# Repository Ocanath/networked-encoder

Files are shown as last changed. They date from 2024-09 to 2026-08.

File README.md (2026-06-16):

# Networked Encoder

A compact RS-485 magnetic encoder system powered by [DARTT](https://github.com/ocanath/dartt-protocol), designed for daisy-chaining multiple encoder nodes on a shared bus. The system consists of STM32-based firmware, a host-side C++ API, and a CLI tool for calibration, address assignment, and firmware flashing.

## What it does

Each encoder node sits on an RS-485 bus and responds to two address classes:

- **Motor address** — a minimal framing mode optimized for high-rate angle polling, intended for real-time motion control.
- **Misc address** — full DARTT register access for calibration (sin/cos bounds, angular offset, orthogonality error), device control (save to flash, restart, enter bootloader), and diagnostics.

Addresses are assigned per-device and persisted to flash. The bootloader (also DARTT-based) supports firmware updates over the same RS-485 bus with no additional hardware interface.

## Repository Structure

| Path | Contents |
|---|---|
| `embedded/encoder-rs485` | STM32G031 encoder application firmware |
| `embedded/encoder-bootloader` | DARTT-based RS-485 bootloader |
| `api/` | Host-side C++ encoder controller library |
| `cli/` | Command-line tool for calibration, addressing, and flashing |
| `scripts/` | Helper scripts for first-time device setup and firmware updates |

## Dependencies

The API and CLI pull in three submodules under `api/external/`:

| Submodule | Purpose |
|---|---|
| [`dartt-protocol`](https://github.com/ocanath/dartt-protocol) | DARTT framing, parsing, read/write helpers |
| [`byte-stuffing`](https://github.com/ocanath/byte-stuffing) | COBS encode/decode |
| [`serial-cross-platform`](https://github.com/ocanath/serial-cross-platform) | Cross-platform serial port |

Initialize all submodules after cloning with `git submodule update --init --recursive`.

## Building

Requires CMake 3.22+ and a C++20-capable compiler. The primary build target is `encoder-cli`. VSCode launch and build tasks are provided in `.vscode/`.

## CLI

The CLI (`encoder-cli`) takes a DARTT device address as its first argument followed by a port and baud rate. It supports streaming angle data, reading raw ADC values, running an interactive calibration session, reassigning device addresses, and flashing firmware over RS-485 via the bootloader. Run `encoder-cli --help` for the full command reference.

## First-time Device Setup

Use `scripts/init_flash.sh` to set up a brand-new device. The bootloader ships at address 255 and the encoder application defaults to address 0. The script flashes firmware, starts the application, then assigns a permanent address. For subsequent updates on an already-configured device, use `scripts/update_firmware.sh`.

## Using the API

`api/` is designed to be consumed as a CMake `add_subdirectory` dependency. Link against `encoder_controller` and construct an `Encoder` object with the device address and a pointer to an already-connected `Serial` object. The caller owns the `Serial` lifetime.

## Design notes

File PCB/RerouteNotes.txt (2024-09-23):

1. Break pads out to the encoder case for programming
2. instead of terminating fsr wires at current location, split another branch out at 90 degrees and wrap it to the top of the encoder case so the existing 
	wire guides/channel can be used; it just terminates the wires at a different location
3. add a branch somewhere for the temperature sensor

4. Do board to board connector for the aenc to the new 12mm motor encoder, like how in phones are done like yeah good
5. 7pin df52 exits 12mm motor encoder, and does df52 to pico-blade to hand. 7pin has 3.3, gnd, UART, cos, sin, SDA, SCL. SDA and SCL are normally unpopulated
6. for the fsr foldover, do a picolock that sits on the top of the drive train case as well as a solder version

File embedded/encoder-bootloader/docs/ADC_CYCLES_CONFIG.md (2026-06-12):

# ADC Sample Time Configuration

## This section was written by a human

WARNING: This document was fully generated by claude. Review the contents before acting on them.

I haven't been thinking about the cycle time for SAR adc's right. It's about impedance matching/settling time... claude caught this in a review and it's something to think about.

## Background

The STM32G031 ADC requires a minimum sampling time for the internal sampling
capacitor to charge to within 0.5 LSB of the input voltage. The required time
depends on source impedance:

```
t_SAMPLE ≥ (R_ADC + R_SOURCE) × C_ADC × ln(2^(N+2))
```

**G031 constants** (from RM0444 / DS12994):
- `R_ADC` ≈ 6 kΩ (internal switch resistance)
- `C_ADC` ≈ 7 pF (sampling capacitor)
- `N` = 12 (ADC resolution in bits)
- `ln(2^14)` ≈ 9.70

**ADC clock**: PCLK/2 = 64 MHz/2 = **32 MHz** → 1 cycle = 31.25 ns

## Source Impedance vs. Minimum Sample Time

| Sample time | Duration @ 32 MHz | Max R_SOURCE |
|---|---|---|
| 1.5 cycles | 47 ns | insufficient for any source |
| 7.5 cycles | 234 ns | insufficient |
| 12.5 cycles | 391 ns | ~0 Ω |
| 19.5 cycles | 609 ns | ~3 kΩ |
| **39.5 cycles** | **1234 ns** | **~12 kΩ** |
| 79.5 cycles | 2484 ns | ~31 kΩ |

## Current Setting

`ADC_SAMPLETIME_39CYCLES_5` — chosen to cover direct encoder outputs and
typical RC anti-alias filter resistors (e.g. 4.7 kΩ series + shunt cap).

With 4× oversampling this yields a total conversion time of:

```
4 × (39.5 + 12.5) = 208 ADC cycles ≈ 6.5 µs per channel
2 channels × 6.5 µs ≈ 13 µs per DMA batch
```

## Recalculating for a Different Source Impedance

Solve for the minimum number of ADC cycles:

```
t_SAMPLE = (R_ADC + R_SOURCE) × C_ADC × ln(2^14)
         = (6000 + R_SOURCE) × 7e-12 × 9.70

cycles = ceil(t_SAMPLE × f_ADC) + 0.5   (round up to next available setting)
```

Then pick the next available `ADC_SAMPLETIME_*` value above that cycle count.
If source impedance is unknown, measure or bound it from the schematic
(series resistors, output driver spec of the encoder IC).

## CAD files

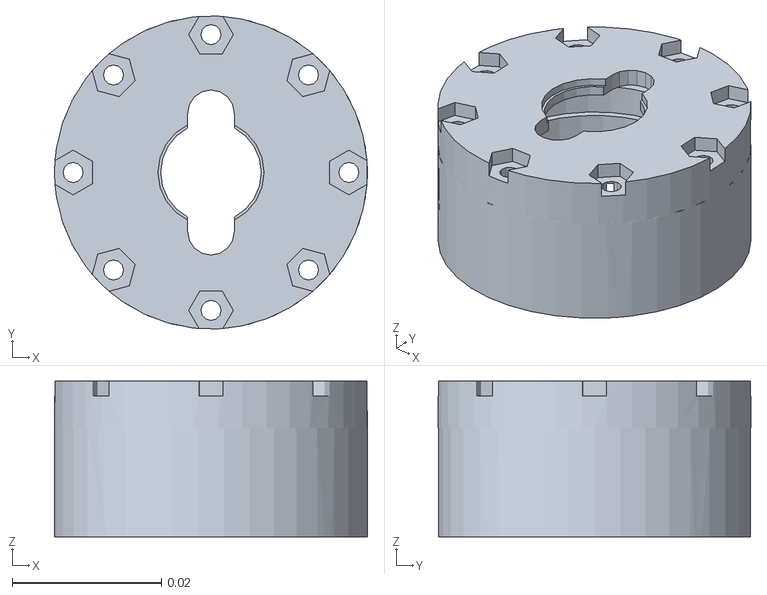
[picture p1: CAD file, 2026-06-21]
CAD/stl/stator-coarse.STL
0.042 x 0.042 x 0.0209

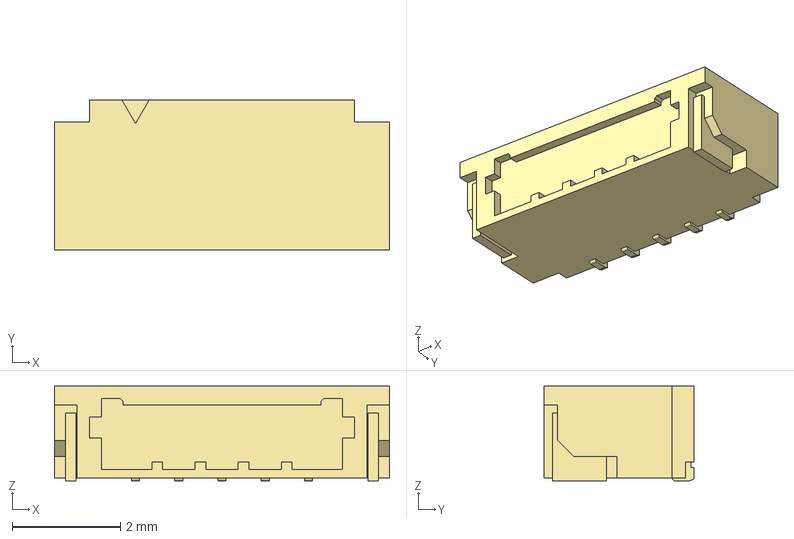
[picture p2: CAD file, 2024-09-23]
PCB/3dModels/DF52 CAD Download/DF52-5S-0.8H.stp
6.20 x 2.77 x 1.75 mm

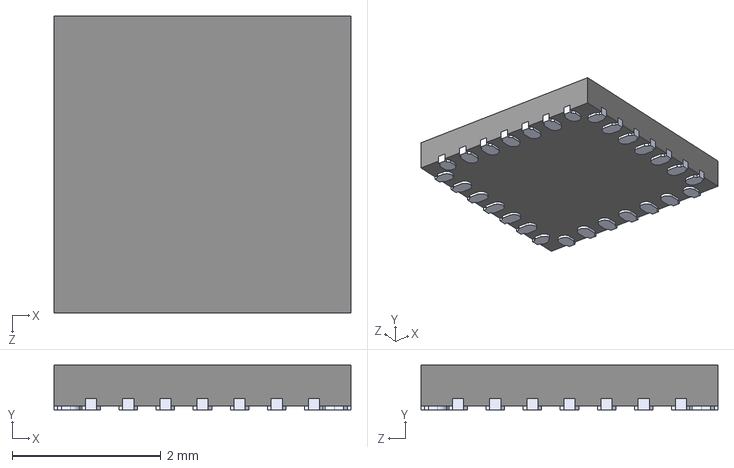
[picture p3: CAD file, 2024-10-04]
PCB/3dModels/STM32G031G6U6.step
4.00 x 0.6 x 4.00 mm

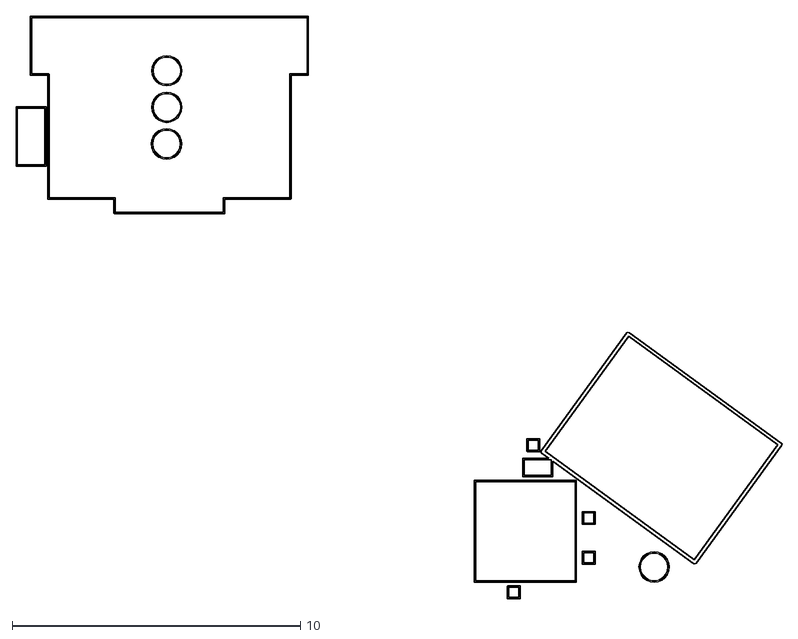
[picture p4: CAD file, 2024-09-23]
PCB/stiffener/adapter-encoder-pcb-F_Courtyard.dxf
26.6 x 20.2

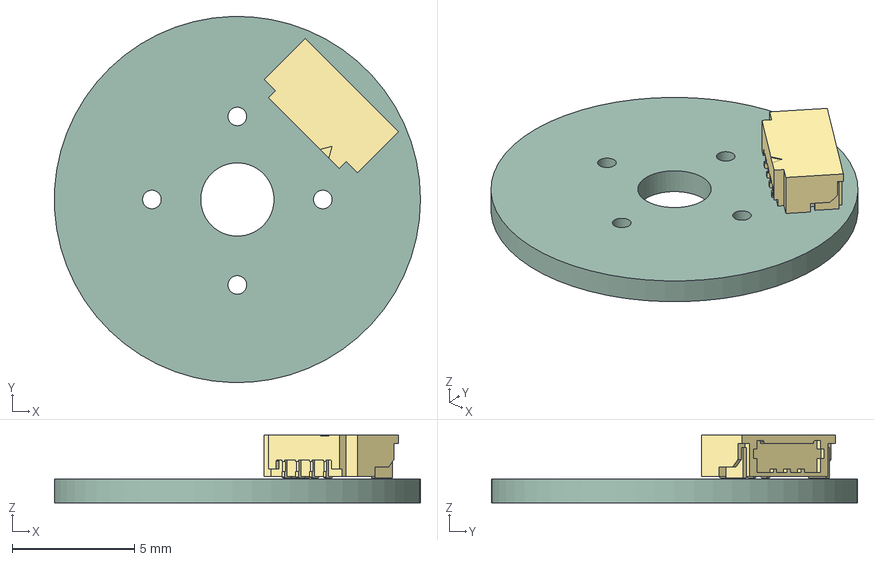
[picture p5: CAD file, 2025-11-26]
PCB/z1-encoder-passthrough-pcb.step
15.0 x 15.0 x 2.78 mm
z1-encoder-passthrough-pcb PCB

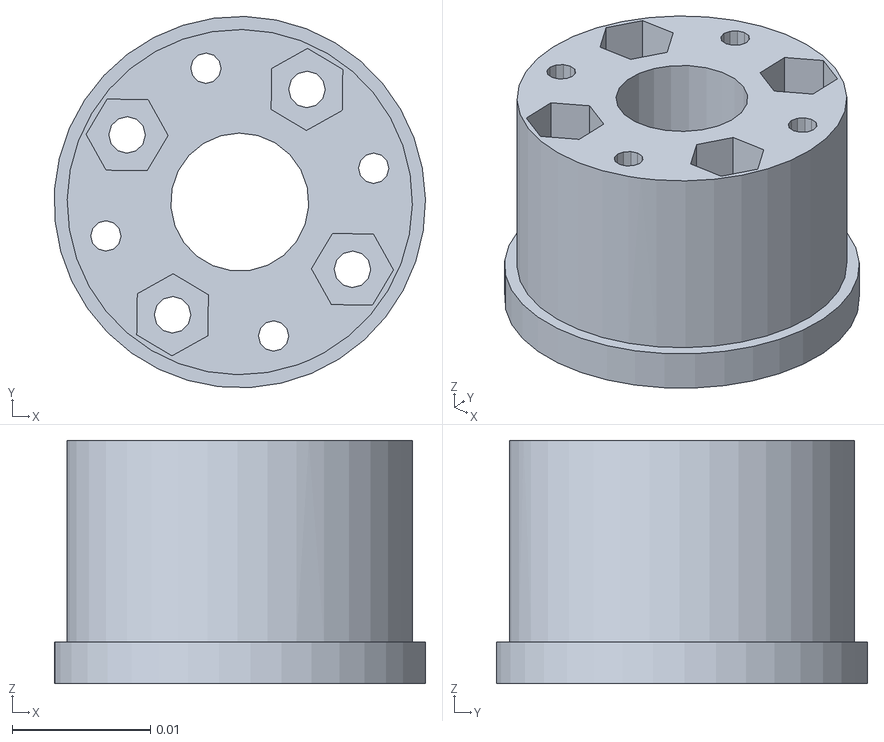
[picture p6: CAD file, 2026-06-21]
CAD/stl/rotor-coarse.STL
0.0269 x 0.0269 x 0.0176

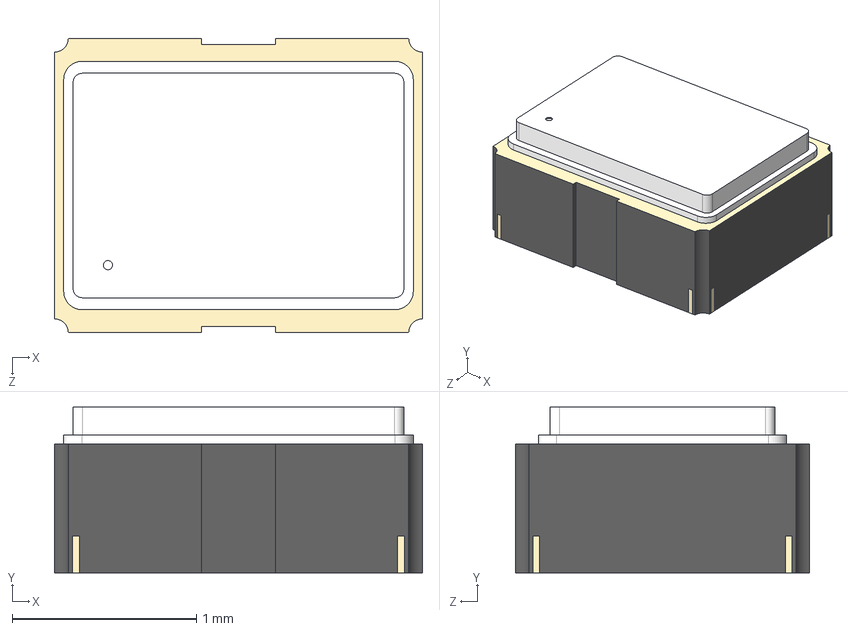
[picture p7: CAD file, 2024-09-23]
PCB/3dModels/ECS-1633-480-BN-TR.STEP
2.00 x 0.9 x 1.60 mm

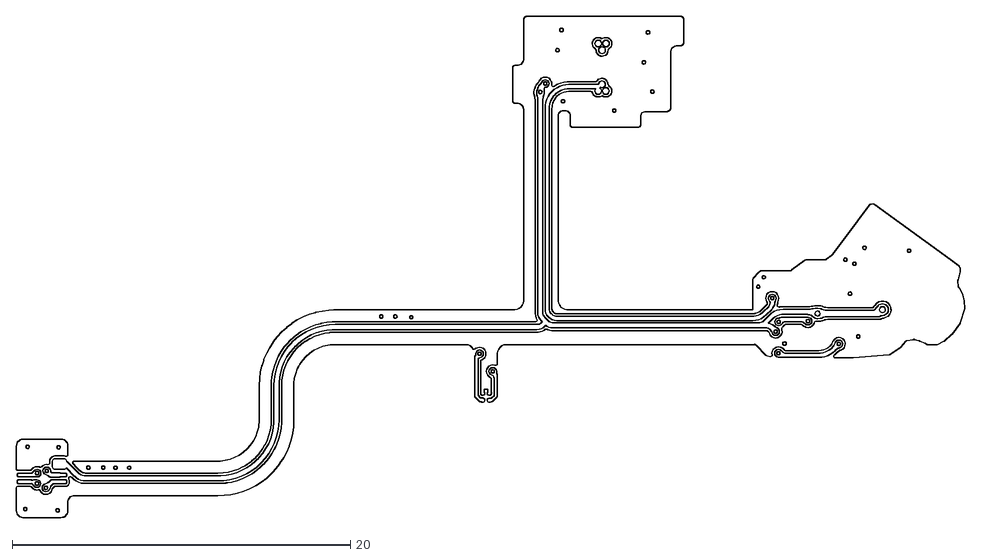
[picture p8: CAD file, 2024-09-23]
PCB/stiffener/adapter-encoder-pcb-B_Cu.dxf
56.0 x 29.6

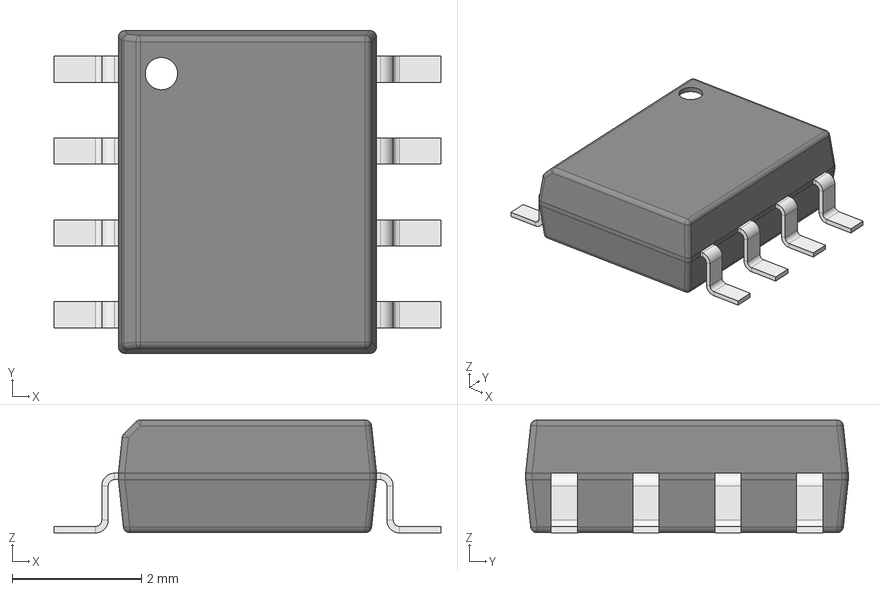
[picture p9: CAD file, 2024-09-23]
PCB/3dModels/SOIC127P600X175-8L.step
6.00 x 5.00 x 1.75 mm
Leader x 8

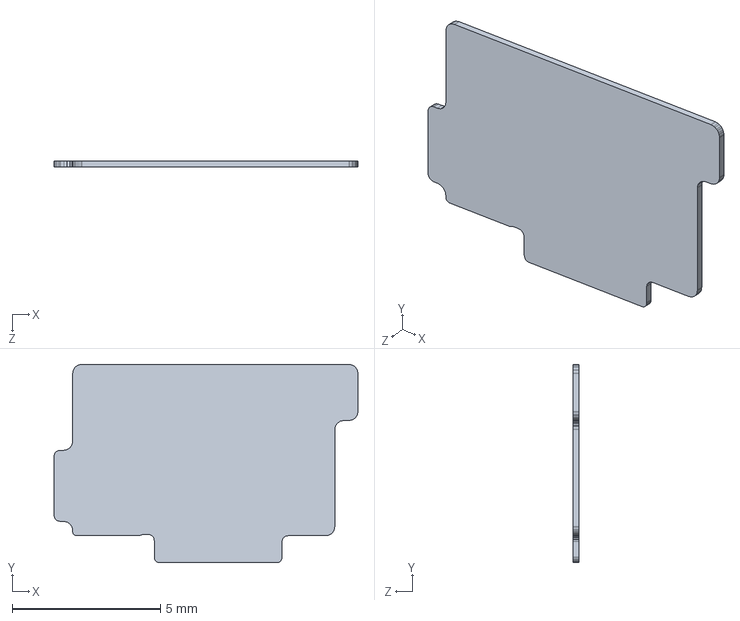
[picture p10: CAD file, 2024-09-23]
PCB/stiffener/Stiffener-4.SLDPRT
10.3 x 6.69 x 0.2 mm

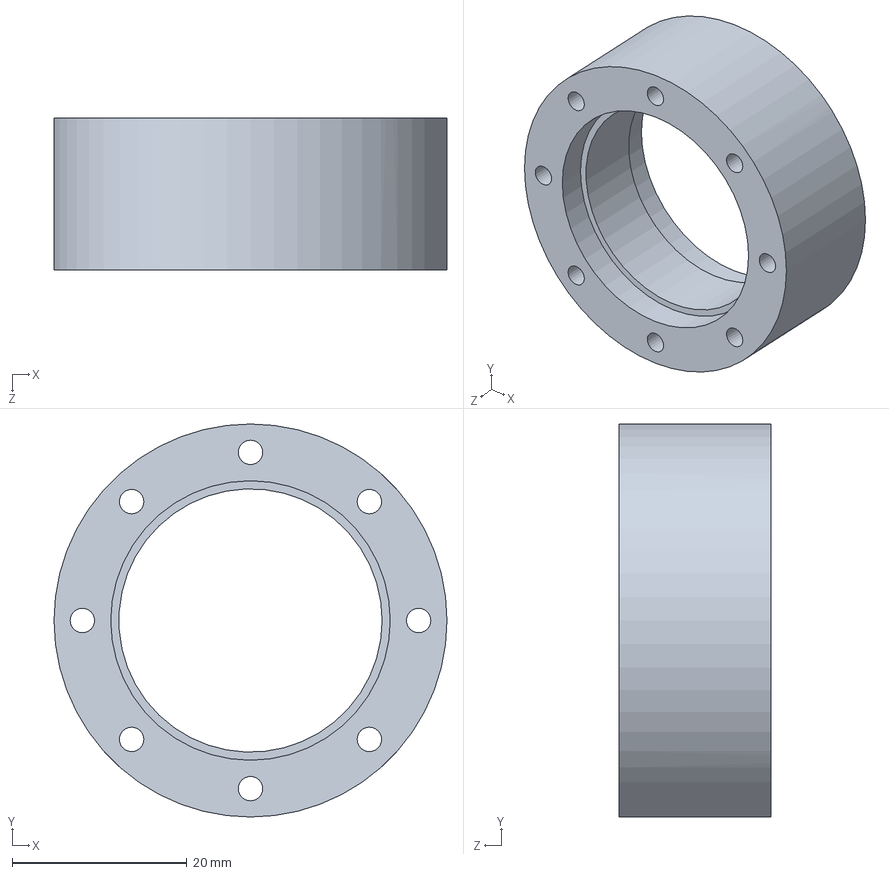
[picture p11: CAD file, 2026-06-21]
CAD/BEARING-SEATS.SLDPRT
45.0 x 45.0 x 17.4 mm

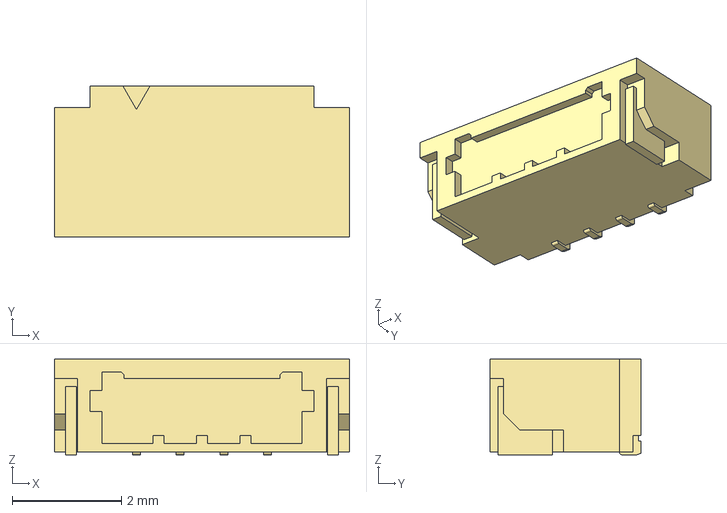
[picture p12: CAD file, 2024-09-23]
PCB/3dModels/DF52-4S-0.8H.stp
5.40 x 2.77 x 1.75 mm

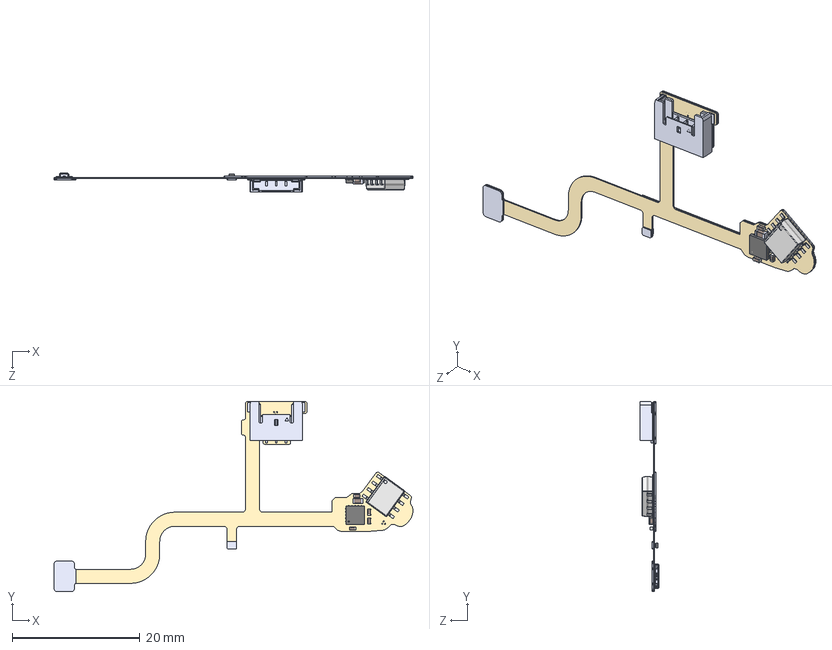
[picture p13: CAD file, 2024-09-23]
PCB/stiffener/adapter-encoder-pcb-outline.STEP
56.2 x 29.8 x 2.91 mm
SOLID^C_0402_1005Metric_adapter-encoder-pcb-outline(2)_adapter-encoder-pcb-outline x 4
SOLID-0^C_0603_1608Metric_adapter-encoder-pcb-outline(2)_adapter-encoder-pcb-outline
SOLID-1^ST_UFQFPN-20_3x3mm_P0.5mm_adapter-encoder-pcb-outline(2)_adapter-encoder-pcb-outline
COMPOUND^SOIC127P600X175-8L_adapter-encoder-pcb-outline(2)_adapter-encoder-pcb-outline
COMPOUND-2^5040500391_adapter-encoder-pcb-outline(2)_adapter-encoder-pcb-outline
SOLID-3^WLP-4_0.83x0.83mm_P0.4mm_adapter-encoder-pcb-outline(2)_adapter-encoder-pcb-outline
SOLID-4^c-2386587-1-1-3d_adapter-encoder-pcb-outline(2)_adapter-encoder-pcb-outline
_autosave-adapter-encoder-pcb PCB^adapter-encoder-pcb-outline(2)_adapter-encoder-pcb-outline
Stiffener-1
Stiffener-2
Stiffener-3
Stiffener-4

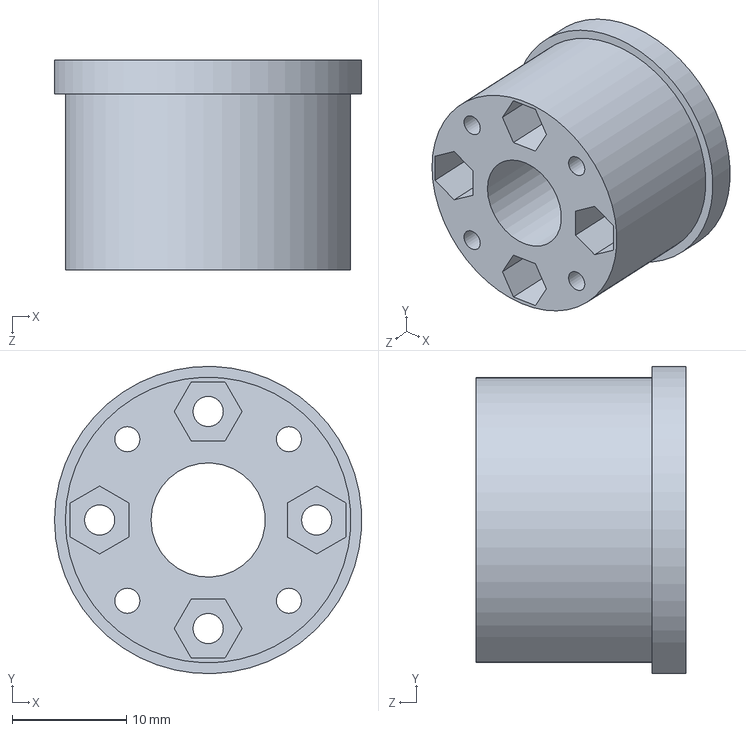
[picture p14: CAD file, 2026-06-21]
CAD/SHAFT.SLDPRT
26.9 x 26.9 x 18.4 mm

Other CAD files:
CAD/encoder.SLDASM
CAD/z1-encoder-passthrough-pcb.step.SLDPRT
PCB/3dModels/c-2386586-1-1-3d.stp
PCB/stiffener/adapter-encoder-pcb-User_4.dxf
CAD/6656K108_Ultra-Thin Ball Bearing.SLDPRT
CAD/90591A265_Zinc-Plated Steel Hex Nut.SLDPRT
CAD/90591A270_Zinc-Plated Steel Hex Nut.SLDPRT
CAD/91290A108_Alloy Steel Socket Head Screw.SLDPRT
CAD/91292A031_18-8 Stainless Steel Socket Head Screw.SLDPRT
CAD/PCBHOLDER.SLDPRT
CAD/adapter-encoder-pcb-outline.step.SLDPRT
CAD/fenc-ring-magnet.SLDPRT
PCB/3dModels/5040500391.step
PCB/3dModels/532610471.stp
PCB/3dModels/ASV.step
PCB/3dModels/CAP_8SIZECODEF.stp
PCB/3dModels/C_0402_1005Metric.step
PCB/3dModels/C_0603_1608Metric.step
PCB/3dModels/DF52-8S-0.8H_21_.step
PCB/3dModels/DFN-10-1EP_3x3mm_P0.5mm_EP1.65x2.38mm.step
PCB/3dModels/DI100N10PQ.STEP
PCB/3dModels/LED_0603_1608Metric.step
PCB/3dModels/PCC-M0530M-LP.STEP
PCB/3dModels/RNM0015A.stp
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

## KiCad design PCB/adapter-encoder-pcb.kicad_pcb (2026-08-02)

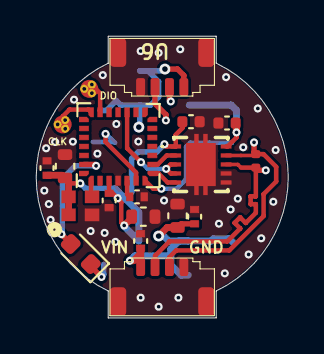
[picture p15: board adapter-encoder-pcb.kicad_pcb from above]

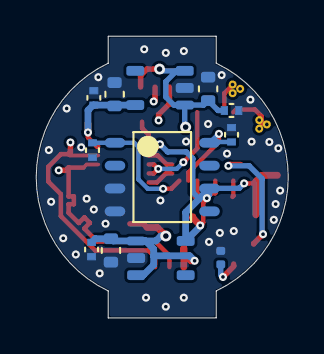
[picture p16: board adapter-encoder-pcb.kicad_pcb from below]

Board: 4 copper layers, 14.0 x 15.6 mm, 31 parts (12 on the bottom side), 17 nets.

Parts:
C1, C8, C10, C12, C15, C17: 4.7uF; C_0603_1608Metric
C2, C3, C4, C5, C6, C7, C9, C11, C13, C14, C16, C18: 100nF; C_0402_1005Metric
D1: LED; LED_0603_1608Metric
IC1: THVD2410VDRCR
M1, M2: THRU_HOLE_PAD; PAD-SMT-SMALL
R1: Resistor; R_0402_1005Metric
R3: 120; R_0402_1005Metric
U1: TLE5009E1000FUMA1; SOIC8-TLE5009
U2: STM32G031G6U6; UFQFPN28
U3, U6: DF52-4S-0.8H(21)
U4, U7: SPX3819M5-L-3-3; SOT-23-5
U5: C2901617; ECS-1633-480-BN-TR

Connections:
+3V3: C1.1, C3.1, C6.2, C12.1, C13.1, IC1.1 (VIO), U1.6 (Vdd), U2.3 (VDD), U4.5 (VOUT), U5.1 (Enable/Disable), U5.4 (VDD)
/+5V0: C7.2, C16.1, C17.1, IC1.10 (VCC), U7.5 (VOUT)
/COS: C2.1, U1.1 (COS_P), U2.7 (PA1)
/LED_GPIO: D1.2 (A), U2.27 (PB7)
/RS485+: IC1.8 (A), R3.1, U3.2, U6.2
/RS485-: IC1.9 (B), R3.2, U3.3, U6.3
/RX: IC1.2 (R), U2.9 (PA3)
/SIN: C4.1, U1.8 (SIN_P), U2.6 (PA0)
/SWCLK: M2.1, U2.20 (PA13)
/SWDIO: M1.1, U2.21 (PA14-BOOT0)
/TX: IC1.5 (D), U2.8 (PA2)
/UART1_DE: IC1.3 (DE), IC1.4 (~RE), U2.17 (PC6)
/Vin: C8.1, C9.1, C10.1, C11.1, C14.1, C15.1, C18.1, U3.1, U4.1 (VIN), U4.3 (EN), U6.1, U7.1 (VIN), U7.3 (EN)
GND: C1.2, C2.2, C3.2, C4.2, C5.2, C6.1, C7.1, C8.2, C9.2, C10.2, C11.2, C12.2, C13.2, C14.2, C15.2, C16.2, C17.2, C18.2, IC1.6 (GND), IC1.7 (SLR), IC1.11 (EP_1), IC1.12 (EP_2), IC1.13 (EP_3), IC1.14 (EP_4), IC1.15 (EP_5), R1.2, U1.3 (GND2), U1.4 (GND1), U2.4 (VSS), U3.4, U3.5 (MNT), U3.6 (MNT), U4.2 (GND), U5.2 (GND/Case), U6.4, U6.5 (MNT), U6.6 (MNT), U7.2 (GND)
unnamed: D1.1 (K), R1.1
unnamed: U2.1 (PC14-OSC32_IN), U5.3 (OUTPUT)
unnamed: C5.1, U2.5 (PF2-NRST)

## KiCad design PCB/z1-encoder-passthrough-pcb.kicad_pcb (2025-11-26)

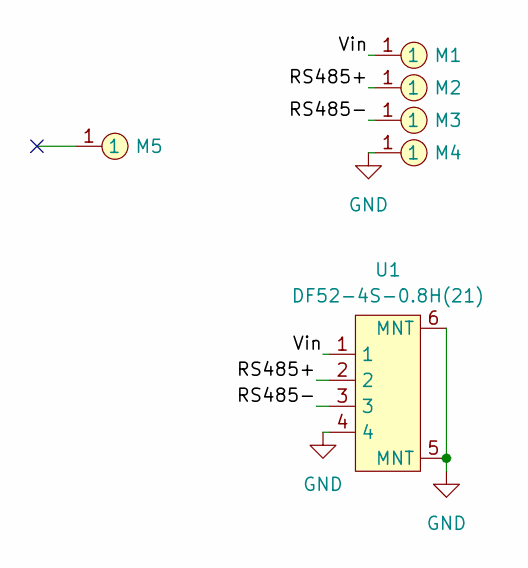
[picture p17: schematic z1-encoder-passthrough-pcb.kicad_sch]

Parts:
M1, M2, M3, M4: THRU_HOLE_PAD; THRU_HOLE
M5: THRU_HOLE_PAD; MECH_THRU_HOLE
U1: DF52-4S-0.8H(21)

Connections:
/RS485+: M2.1, U1.2
/RS485-: M3.1, U1.3
/Vin: M1.1, U1.1
GND: M4.1, U1.4, U1.5 (MNT), U1.6 (MNT)

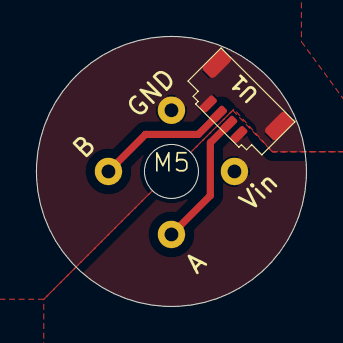
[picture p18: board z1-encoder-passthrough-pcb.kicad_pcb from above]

Board: 2 copper layers, 15.0 x 15.0 mm, 6 parts (0 on the bottom side), 4 nets.

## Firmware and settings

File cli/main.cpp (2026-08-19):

#include <iostream>
#include <string>
#include <signal.h>
#include "args.h"

static volatile sig_atomic_t g_stop = 0;
static void on_sigint(int) { g_stop = 1; }
#include "encoder.h"
#include "dartt_map.h"
#include "dartt_flasher.h"
#include "serial.h"

int main(int argc, char ** argv)
{
    cli_args_t a;
    parse_args(argc, argv, a);

    Serial ser;
    if (a.port) ser.connect(a.port, a.baud);
    else        ser.autoconnect(a.baud);

    Encoder enc(a.addr, &ser);

    if (a.read_angle)
    {
        while(1)
        {
            // int rc = enc.read_angle_misc();
			int rc = enc.read_angle();
            if(rc == 0)
            {
                printf("theta= %f\n", enc.theta);
            }
            else
            {
                printf("Error reading from encoder %d\n", rc);
            }
        }
    }
    if (a.read_angle_misc)
    {
        while(1)
        {
            int rc = enc.read_angle_misc();
            if(rc == 0)
            {
                printf("theta= %f\n", enc.theta);
            }
            else
            {
                printf("Error reading from encoder %d\n", rc);
            }
        }
    }
    if (a.read_adc)
    {
        while(1)
		{
			int rc = enc.read_adc_raw();
			if(rc == 0)
			{
				printf("[%d %d]\n", enc.dp_periph.dma_adc_raw[0], enc.dp_periph.dma_adc_raw[1]);
			}
			else
			{
				printf("Error reading %d\n", rc);
			}
		}
    }
    if (a.read_fds)
    {
        printf("Placeholder: TODO read out fds\n");
    }
    if (a.set_zero)
    {
        printf("Zero out encoder\n");
		float avg = 0;
		int nsamples = 0;
		int rc = 0;
		for(int ang_sample = 0; ang_sample < 1000; ang_sample++)
		{
			rc = enc.read_angle_misc();
			if(rc == 0)
			{
				avg += enc.dp_periph.angle;
				nsamples++;
			}
		}
		avg = avg / (float)nsamples;
		printf("avg = %f\n", avg);

		dartt_mem_t offset_slice ={.buf = (unsigned char *)&enc.dp_ctl.fds.offset,
			.size = sizeof(enc.dp_ctl.fds.offset)
		};
		rc = dartt_read_multi(&offset_slice, &enc.ds);
		if(rc != 0) 
		{
			printf("issue reading offset, abort\n");
			return -1;
		}
		printf("offset is equal to %d\n",enc.dp_periph.fds.offset);
		float offset = (float)enc.dp_periph.fds.offset;
		float raw = avg + offset;
		enc.dp_ctl.fds.offset = (int32_t)raw;

		rc = dartt_write_multi(&offset_slice, &enc.ds);
		printf("Wrote %d as offset\n", enc.dp_ctl.fds.offset);
		rc = enc.write_action_flag(FS_SAVE);
		if(rc != 0) {printf("FS_SAVE failed: %d\n", rc);}
		else{printf("Updated filesystem successfully\n");}


    }
    if (a.calibrate)
    {
		signal(SIGINT, on_sigint);
		int32_t sinmin = 1<<14;
		int32_t sinmax = 0;
		int32_t cosmin = 1 << 14;
		int32_t cosmax = 0;
		while(!g_stop)
		{
			int rc = enc.read_adc_raw();
			if(rc != 0)
			{
				printf("Error reading %d\n", rc);
			}
			int32_t c = enc.dp_periph.dma_adc_raw[0];
			int32_t s = enc.dp_periph.dma_adc_raw[1];
			if(c < cosmin)
			{
				cosmin = c;
			}
			if(c > cosmax)
			{
				cosmax = c;
			}
			if(s < sinmin)
			{
				sinmin = s;
			}
			if(s > sinmax)
			{
				sinmax = s;
			}
			printf("min = [%d, %d], max = [%d, %d]\n", cosmin, sinmin, cosmax, sinmax);
		}
		printf("\nFinal: cos=[%d, %d] sin=[%d, %d]\n", cosmin, cosmax, sinmin, sinmax);
		enc.dp_ctl.fds.cos_min = cosmin;
		enc.dp_ctl.fds.cos_max = cosmax;
		enc.dp_ctl.fds.sin_min = sinmin;
		enc.dp_ctl.fds.sin_max = sinmax;
		dartt_mem_t sincos_minmax = {
			.buf = (unsigned char *)(&enc.dp_ctl.fds.sin_min),
			.size = 4*sizeof(uint32_t)
		};
		int rc = dartt_write_multi(&sincos_minmax, &enc.ds);
		// int rc = enc.write_fds();
		if(rc != 0) printf("write_fds failed: %d\n", rc);
		rc = enc.write_action_flag(FS_SAVE);
		if(rc != 0) printf("FS_SAVE failed: %d\n", rc);
    }
    if (a.restart)
    {
		int	rc = enc.write_action_flag(RESTART);
		if(rc != 0) printf("RESTART failed: %d\n", rc);

    }
    if (a.bootload)
    {
		int	rc = enc.write_action_flag(BOOTLOAD);
		if(rc != 0) printf("BOOTLOAD failed: %d\n", rc);
    }
    if (a.set_address)
    {
        printf("Placeholder: set address to %d\n", a.new_address);

		enc.dp_ctl.fds.address = a.new_address;
		dartt_mem_t addr = {
			.buf = (unsigned char *)(&enc.dp_ctl.fds.address),
			.size = sizeof(enc.dp_ctl.fds.address)
		};
		int rc = dartt_write_multi(&addr, &enc.ds);
		if(rc != 0 ){printf("address update failed: %d\n", rc);}
		//TODO: add write action to update flash HERE but don't do it yet to avoid brickage
		rc = enc.write_action_flag(FS_SAVE);
		if(rc != 0 ){printf("settings save failed code: %d\n", rc);}

		//set long timeout and read back address to confirm
		enc.ds.timeout_ms = 1000;
		rc = dartt_read_multi(&addr, &enc.ds);
		if(rc != 0){printf("Readback post save failed: %d\n", rc);}
		if(enc.dp_periph.fds.address != a.new_address)
		{
			printf("Failed to write - readback mismatch. desired %d, actual %d\n", a.new_address, enc.dp_periph.fds.address);
		}
		else
		{
			printf("Readback match\n");
		}
		
		rc = enc.write_action_flag(BOOTLOAD);
		if(rc != 0 ){printf("bootload update failed: %d\n", rc);}

		DarttFlasher flasher(a.bootloader_addr, &ser);
		rc = flasher.poll_action_flags(500);
		if(rc < 0)
		{
			printf("Failed to get action flag: %d\n", rc);
			return rc;
		}
		else{printf("bootloader ready, writing address\n");}
		rc = flasher.update_target_address(a.new_address);
		if(rc != 0) {printf("Failed to update bootloader address. Code %d\n", rc);}
		rc = flasher.start_app();
		if(rc != 0) {printf("Failed to start app, code %d\n", rc);}
		printf("Done\n");
    }
    if (a.flash)
    {
        printf("Placeholder: flash %s via bootloader\n", a.filename);
    }
    if (a.bl_version)
    {
        printf("Placeholder: get bootloader version\n");
    }
    if (a.bl_start)
    {
        printf("Placeholder: start application\n");
    }
	if(a.scan)
	{
		for(uint8_t scan_addr = 0; scan_addr < 255; scan_addr++)
		{
			Encoder scan_enc(scan_addr, &ser);
			int s_rc = scan_enc.read_adc_raw();
			if(s_rc == 0)
			{
				printf("Found encoder %d\n", scan_addr);
			}
		}
	}
    return 0;
}

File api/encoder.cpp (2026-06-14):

#include "encoder.h"
#include "uart_config.h"

#define NUM_BYTES_COBS_OVERHEAD	2

Encoder::Encoder(unsigned char addr, Serial * ser)
{
	ds.address = addr;

	ds.ctl_base.buf = (unsigned char *)(&dp_ctl);
	ds.ctl_base.size = sizeof(dartt_map_t);
	ds.periph_base.buf = (unsigned char *)(&dp_periph);
	ds.periph_base.size = sizeof(dartt_map_t);
	for(int i = 0; i < (int)sizeof(dartt_map_t); i++)
	{
		ds.ctl_base.buf[i] = 0;
		ds.periph_base.buf[i] = 0;
	}

	tx_buf_mem = new unsigned char[UART_BUF_SIZE];
	rx_buf_mem = new unsigned char[UART_BUF_SIZE];

	ds.base_offset = 0;
	ds.msg_type = TYPE_SERIAL_MESSAGE;
	ds.tx_buf.buf = tx_buf_mem;
	ds.tx_buf.size = UART_BUF_SIZE - NUM_BYTES_COBS_OVERHEAD;
	ds.tx_buf.len = 0;
	ds.rx_buf.buf = rx_buf_mem;
	ds.rx_buf.size = UART_BUF_SIZE - NUM_BYTES_COBS_OVERHEAD;
	ds.rx_buf.len = 0;
	ds.blocking_tx_callback = &network_encoder::tx_blocking;
	ds.user_context_tx = (void*)(ser);
	ds.blocking_rx_callback = &network_encoder::rx_blocking;
	ds.user_context_rx = (void*)(ser);
	ds.timeout_ms = 10;

	theta = 0.f;

	angle_slice = {
		.buf = (unsigned char *)(&dp_ctl.angle),
		.size = sizeof(dp_ctl.angle),
	};
	adc_slice = {
		.buf = (unsigned char *)(&dp_ctl.dma_adc_raw[0]),
		.size = sizeof(dp_ctl.dma_adc_raw),
	};
	ms_slice = {
		.buf = (unsigned char *)(&dp_ctl.tick),
		.size = sizeof(dp_ctl.tick),
	};
	fds_slice = {
		.buf = (unsigned char *)(&dp_ctl.fds),
		.size = sizeof(dp_ctl.fds),
	};
	offset_slice = {
		.buf = (unsigned char *)(&dp_ctl.fds.offset),
		.size = sizeof(dp_ctl.fds.offset),
	};
	action_slice = {
		.buf = (unsigned char * )(&dp_ctl.action_flag),
		.size = sizeof(dp_ctl.action_flag)
	};
}

Encoder::~Encoder()
{
	delete[] tx_buf_mem;
	delete[] rx_buf_mem;
}

int Encoder::read_angle(void)
{
	Serial * ser = (Serial*)(ds.user_context_tx);
	ds.tx_buf.len = 0;
	ds.tx_buf.buf[ds.tx_buf.len++] = ds.address;
	int rc = append_crc(&ds.tx_buf);
	if(rc != DARTT_PROTOCOL_SUCCESS){return rc;}
	cobs_buf_t cb_tx = {
		.buf = ds.tx_buf.buf,
		.size = ds.tx_buf.size,
		.length = ds.tx_buf.len,
		.encoded_state = COBS_DECODED
	};
	rc = cobs_encode_single_buffer(&cb_tx);
	if(rc != DARTT_PROTOCOL_SUCCESS){return rc;}
	ser->write(cb_tx.buf, cb_tx.length);

	cobs_buf_t cb_enc =
	{
		.buf = ds.rx_buf.buf,
		.size = UART_BUF_SIZE,
		.length = 0
	};

	rc = ser->read_until_delimiter(cb_enc.buf, cb_enc.size, 0, ds.timeout_ms);
	if (rc >= 0)
	{
		cb_enc.length = rc;
	}
	else if (rc == -2)
	{
		return -7;
	}
	else
	{
		return -1;
	}
	cobs_buf_t cb_dec =
	{
		.buf = ds.rx_buf.buf,
		.size = ds.rx_buf.size,
		.length = 0
	};
	rc = cobs_decode_double_buffer(&cb_enc, &cb_dec);
	ds.rx_buf.len = cb_dec.length;
	if(rc != COBS_SUCCESS)
	{
		return rc;
	}
	if(cb_dec.buf[0] != MASTER_MOTOR_ADDRESS)
	{
		printf("addr mismatch\n");
	}
	uint16_t raw = (uint16_t)cb_dec.buf[1] | ((uint16_t)cb_dec.buf[2] << 8);
	theta = ((float)(int16_t)raw) / ((float)(1 << 13));
	return 0;
}

int Encoder::read_angle_misc(void)
{
	int rc = dartt_read_multi(&angle_slice, &ds);
	if(rc != DARTT_PROTOCOL_SUCCESS)
	{
		return rc;
	}
	theta = ((float)dp_periph.angle) / ((float)(1 << 14));
	return rc;
}

int Encoder::write_action_flag(uint32_t action)
{
	dp_ctl.action_flag = action;
	return dartt_write_multi(&action_slice, &ds);
}

int Encoder::read_adc_raw(void)
{
	return dartt_read_multi(&adc_slice, &ds);
}

int Encoder::read_time_data(void)
{
	return dartt_read_multi(&ms_slice, &ds);
}

int Encoder::write_fds(void)
{
	return dartt_write_multi(&fds_slice, &ds);
}

int Encoder::write_offset(void)
{
	return dartt_write_multi(&offset_slice, &ds);
}

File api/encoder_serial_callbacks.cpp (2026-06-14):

#include "encoder_serial_callbacks.h"
#include "serial.h"
#include <cstdio>
#include "uart_config.h"

namespace network_encoder {

int tx_blocking(unsigned char addr, dartt_buffer_t * b, void * user_context, uint32_t timeout)
{
	if(user_context == NULL)
	{
		return -2;
	}
	Serial * pser = (Serial*)(user_context);
	if(pser->connected() == false)
	{
		return -2;
	}
	cobs_buf_t cb = {
		.buf = b->buf,
		.size = UART_BUF_SIZE,
		.length = b->len,
		.encoded_state = COBS_DECODED
	};
	int rc = cobs_encode_single_buffer(&cb);
	if (rc != 0)
	{
		return rc;
	}

	rc = pser->write(cb.buf, (int)cb.length);
	if(rc == (int)cb.length)
	{
		return DARTT_PROTOCOL_SUCCESS;
	}
	else
	{
		return -1;
	}
}

int rx_blocking(dartt_buffer_t * buf, void * user_context, uint32_t timeout)
{
	if(user_context == NULL)
	{
		return -2;
	}
	Serial * pser = (Serial*)(user_context);
	if(pser->connected() == false)
	{
		return -2;
	}

	cobs_buf_t cb_enc =
	{
		.buf = buf->buf,
		.size = UART_BUF_SIZE,
		.length = 0
	};

	int rc;
	rc = pser->read_until_delimiter(cb_enc.buf, cb_enc.size, 0, timeout);

	if (rc >= 0)
	{
		cb_enc.length = rc;
	}
	else if (rc == -2)
	{
		return -7;
	}
	else
	{
		return -1;
	}

	cobs_buf_t cb_dec =
	{
		.buf = buf->buf,
		.size = buf->size,
		.length = 0
	};
	rc = cobs_decode_double_buffer(&cb_enc, &cb_dec);
	buf->len = cb_dec.length;

	if (rc != COBS_SUCCESS)
	{
		return rc;
	}
	else
	{
		return DARTT_PROTOCOL_SUCCESS;
	}
}

} // namespace network_encoder

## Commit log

2024-09-23 init commit
    [101-003 M3 T-ULPS.SLDPRT, 101-003 M3 T-ULPS.STEP, 105-002 Drivetrain Bearing 3mm ID 6mm OD.SLDPRT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]
2024-10-03 new STM32, not enough RAM on the shitty L0. will probably need a little more OD but thats ok
    [adapter-encoder-pcb.kicad_sch]
2024-10-04 mostly routed updated board
    [ECS-1633-480-BN-TR - Copy.STEP, STM32G031G6U6.step, adapter-encoder-pcb.kicad_pcb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]
2024-10-04 deleted unnecessary files, updated board outline, drc passes
    [101-003 M3 T-ULPS.SLDPRT, 101-003 M3 T-ULPS.STEP, 105-002 Drivetrain Bearing 3mm ID 6mm OD.SLDPRT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]
2024-10-04 some minor tweaks
    [adapter-encoder-pcb.kicad_pcb]
2024-10-12 length matching rs485
    [adapter-encoder-pcb.kicad_pcb, adapter-encoder-pcb.kicad_sch]
2024-10-13 cad and silkscreen
    [6656K108_Ultra-Thin Ball Bearing.SLDPRT, 98541A440_External Retaining Ring.SLDPRT, SHAFT.SLDPRT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]
2024-10-14 designed the encoder CAD around the large 25mmID bearings
    [90591A270_Zinc-Plated Steel Hex Nut.SLDPRT, 91290A108_Alloy Steel Socket Head Screw.SLDPRT, 98541A440_External Retaining Ring.SLDPRT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]
2024-10-14 updated screwhole style
    [BEARING-SEATS.SLDPRT, PCBHOLDER.SLDPRT]
2024-10-17 updated via size due to jlcpcb complaining about 0.4mm annular ring diameter
    [adapter-encoder-pcb.kicad_pcb]
2025-11-26 created a connector pcb for passthrough!
    [z1-encoder-passthrough-pcb.kicad_pcb, z1-encoder-passthrough-pcb.kicad_sch]
2025-11-26 stackup and step
    [z1-encoder-passthrough-pcb.kicad_pcb, z1-encoder-passthrough-pcb.step]
2025-11-26 passthrough with pcb - pcb orderable and this is printable
    [z1-encoder-passthrough-pcb.kicad_pcb, z1-encoder-passthrough-pcb.step]
2026-06-07 moved to pcb directory for this to be top level repo
    [5040500391.step, 532610471.stp, ASV.step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]
2026-06-07 submodule added for networked encoder
2026-06-12 update encoder efw
2026-06-14 wired up serial and read angle
2026-06-14 adc raw
2026-06-14 calibration works
2026-06-14 pin update to bootloader which has public flasher api
2026-06-14 trying motor msg implementation read angle
2026-06-14 firmware updated with read angle motor message
2026-06-17 updated cad!
    [90591A265_Zinc-Plated Steel Hex Nut.SLDPRT, 91292A031_18-8 Stainless Steel Socket Head Screw.SLDPRT, 98541A440_External Retaining Ring.SLDPRT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]
2026-06-20 regen with proper diameter.
    [BEARING-SEATS.SLDPRT, PCBHOLDER.SLDPRT, SHAFT.SLDPRT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]
2026-06-20 modified configurations and display states - created rendring assets
    [BEARING-SEATS.SLDPRT, PCBHOLDER.SLDPRT, SHAFT.SLDPRT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]
2026-06-20 created working urdf
    [encoder.urdf]
2026-06-20 fixed collision primitives to cylinders for easier simulations
    [encoder.urdf]
2026-06-20 print gitignore
2026-06-21 assets in meters now
    [rotor-coarse.STL, stator-coarse.STL]
2026-06-21 solidworks regenerated everything, but added necessary x axis for constraining encoder assy
    [BEARING-SEATS.SLDPRT, PCBHOLDER.SLDPRT, SHAFT.SLDPRT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]
2026-06-21 no threads
    [90591A265_Zinc-Plated Steel Hex Nut.SLDPRT, encoder.SLDASM]
2026-07-28 removed bad biasing resistors
    [adapter-encoder-pcb.kicad_pcb, adapter-encoder-pcb.kicad_sch]
